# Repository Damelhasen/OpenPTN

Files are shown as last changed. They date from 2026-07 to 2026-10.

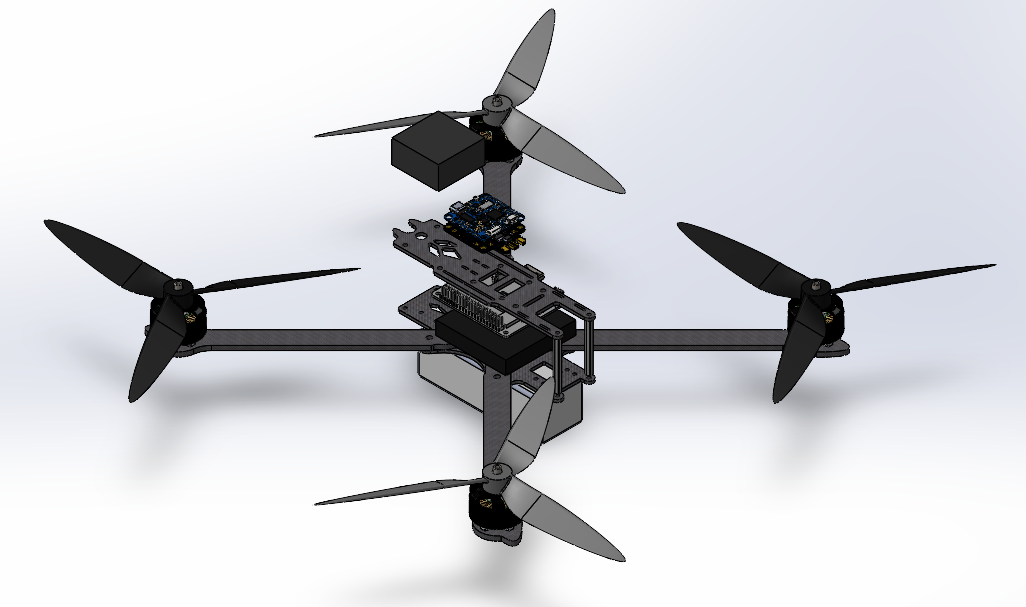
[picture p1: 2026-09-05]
images/drone.png

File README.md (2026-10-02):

  

# **OpenPTN : Radio Survey Drone**
  
The OpenPTN PTN radio survey drone aims to create a drone platform and payload that can complete autonomous flights while sampling directional radio signal strength across the spectrum to triangulate and map radio signals . Existing radio mapping and surveying tools are inaccessible to many due to their high costs and inefficiency due to their ground-based characteristics. 
# Use Cases
Radio surveying is used for:

**Search and Rescue**
-   Emergency Locator Transmitters (ELTs) from aircraft
-   Personal Locator Beacons (PLBs)
-   Emergency Position Indicating Radio Beacons (EPIRBs)

**Interference hunting**
-   Illegal FM Transmitter
-   GNSS jamming/spoofing
-   Malfunctioning Wireless Device
-   Interference Affecting Emergency Communications

**Telemetry tags**
- Wildlife and conservation tracking 
- Model Rocketry 

# System Diagram


# CAD Progress



# Current Hardware 
**Flight Controller**
- Matek H743-SLIM

**Power Distribution Board**
- Matek FCHUB-6S

**GPS Module**
- Matek M10Q GPS

**Electronic Speed Controller**
- Hobbywing XRotor 65A 4-in-1 BLHeli_32 ESC

**Software Defined Radios (SDRs)**
- RTL-SDR Blog V4 - Airspy Mini 

**Video Transmitter (VTX)**
 - AKK FX2 Ultimate 5.8 GHz (25–1000 mW)
 
 

 # Sponsorships

 **Banana Pi Team**

lion-wang-profile-picture-1566954273.avif

The Banana Pi Team has graciously donated their Banana Pi M2,Pro LCD and LED displays, and many other electrical components that will act as the processing unit for our SDR signals 

 **The London Model Aircraft Club**



The London Model Aircraft Club has donated to us:

-    Carbon Fibre Airframe
-   Flight controllers
-   Electronic Speed Controllers
-   Jumper T-16 Transmitter
-   GPS module
-  Radio Module
- Video Module and Camera 

  **RTL-SDR**

 
 
The RTL-SDR team has provided us with the RTL-SDR Starter Kit, which includes:

-   two sets of variable dipole antennas
-   a dipole mount
-   the RTL-SDR dongle
-   an RTL-SDR
-   an SMA extension cable

**Airspy**



The Airspy team has provided us with an Airspy mini dongle 

**AI USE **
Used to write Firmware and Copilot autofill**

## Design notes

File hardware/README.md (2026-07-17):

# MATEKSYS H743-Slim — ArduPilot Setup + Live IMU Dashboard

This documents the full process of getting a Matek H743-Slim flight controller
(factory-flashed with Betaflight) running ArduCopter and streaming live
attitude/GPS telemetry into a custom Python 3D dashboard (`instaimu.py`).

---

## 1. Hardware background

- Board: **Matek H743-Slim** (STM32H743 MCU)
- Ships from the factory with **Betaflight preloaded**, not ArduPilot — this
  is the root cause of most "no heartbeat" / "no MAVLink" issues on a fresh
  board.
- USB enumerates as an **STMicroelectronics Virtual COM Port** while running
  Betaflight (or any firmware using the STM32 USB CDC-ACM driver).
- Status LEDs: solid Red = power (3.3V rail), and normal ArduPilot boot state
  is typically a **flashing blue LED** (green/red solid, blue blinking) which
  means "disarmed, no GPS lock" — this is healthy, not a fault. A repeating
  **red-solid + blue/green alternating 3x** pattern specifically indicates the
  gyro/accelerometer wasn't detected on boot — that *is* a fault.

---

## 2. Windows driver / port setup

1. Plug the board into your PC via USB.
2. Open **Device Manager → Ports (COM & LPT)**.
3. Look for **STMicroelectronics Virtual COM Port (COMx)** — that's your board.
   Ignore Bluetooth serial links and unrelated management ports (e.g. Intel AMT).
4. If you get `OSError(22, 'The semaphore timeout period has expired.')` when
   opening the port:
   - Try a different USB cable (the #1 cause — many cables are charge-only)
   - Try a different USB port (avoid hubs/front-panel headers if possible)
   - Confirm nothing else (Mission Planner, another script, Arduino IDE) has
     the port open already

To list all serial ports and confirm which one is your board:
```powershell
py -c "import serial.tools.list_ports; [print(p.device, '-', p.description) for p in serial.tools.list_ports.comports()]"
```

---

## 3. Flashing ArduPilot (from factory Betaflight)

Since the board has no ArduPilot bootloader yet, Mission Planner's normal
"Install Firmware" flow can't talk to it directly. Instead, flash it at the
raw STM32 DFU level:

### 3.1 Download firmware
Get **`arducopter_with_bl.hex`** (bundles the ArduPilot bootloader + Copter
firmware in one file — needed for this first-time flash) from:
```
https://firmware.ardupilot.org/Copter/stable/MatekH743/
```
> Note: `MatekH743` may not always appear in Mission Planner's built-in board
> list depending on your Mission Planner version — the firmware server always
> has it directly, so this manual download path is the reliable option.

### 3.2 Enter DFU mode
1. Unplug USB
2. Hold the board's **BOOT** button (or bridge the BOOT pad per Matek's pinout
   if your revision doesn't have a physical button)
3. Plug in USB while still holding BOOT
4. Release after ~2 seconds
5. Device Manager should now show **"DFU in FS Mode"** under Universal Serial
   Bus devices (not a COM port anymore)

### 3.3 Driver for DFU mode (Zadig)
If STM32CubeProgrammer doesn't detect the board over USB:
1. Open **Zadig**
2. Select the **DFU** device from the dropdown (distinct from the STM32
   Virtual COM Port — don't touch that one)
3. Driver: **WinUSB**
4. Click **Replace Driver** (or **Install Driver**)

> ⚠️ Only use Zadig/WinUSB on the **DFU** device. Never replace the driver on
> the STM32 Virtual COM Port entry — that one needs to stay on `usbser` or
> Mission Planner/serial tools will lose it entirely.

### 3.4 Flash with STM32CubeProgrammer
Download: https://www.st.com/en/development-tools/stm32cubeprog.html

1. Open STM32CubeProgrammer, select **USB** as connection type, click
   **Connect** (should detect the board in DFU mode)
2. Go to **Erasing & Programming** tab
3. Browse to `arducopter_with_bl.hex`
4. Check **"Run after programming"** (jumps straight to the new firmware
   instead of requiring a manual power cycle)
5. Click **Start Programming**
6. Wait for a success message — the board will disconnect automatically once
   it starts running the new firmware

### 3.5 Confirm the flash
Check Device Manager again — you should now see an **ArduPilot** USB
composite device exposing (at least) two COM ports:
- One labeled **MAVLink** — use this one
- One labeled **SLCAN** — ignore this (CAN-bus passthrough, unrelated)

---

## 4. Connecting in Mission Planner

1. Select the **MAVLink** COM port (not SLCAN) in the top-right dropdown
2. Baud: **115200**
3. Click **Connect**
4. It should grab a heartbeat and pull parameters — this is the point where
   it finally works if you were stuck on Betaflight firmware before
5. Run through initial setup: frame type (e.g. Quad X), accelerometer
   calibration, compass calibration

If you still get `Sequence contains no elements` here, it almost always means
the FC isn't sending valid MAVLink yet — re-check the flash succeeded and the
correct (MAVLink, not SLCAN) port is selected.

---

## 5. Wireless connection options

Once wired setup works, to go wireless:

| Method | Range | Notes |
|---|---|---|
| **ESP8266/ESP32 WiFi bridge** | ~tens of m | Cheapest; wire to a spare UART, flash ArduPilot's WiFi bridge firmware, connect via UDP/TCP in Mission Planner |
| **Bluetooth (HC-05/HC-06)** | ~10m | Wire to spare UART, pairs as a normal Bluetooth COM port — works with existing scripts unchanged |
| **SiK radio (RFD900, HolyBro TX/RX)** | km-scale | Standard for actual flight telemetry; one radio on the FC, one on the PC via USB |
| **ExpressLRS/CRSF "Backpack"** | radio-link range | If your Jumper T16 runs ELRS or TBS Crossfire, an ELRS Backpack module taps the CRSF MAVLink passthrough and forwards it over WiFi to Mission Planner — no separate telemetry radio needed |

Check your T16's RF protocol under **Model Setup → Internal/External RF** —
CRSF/ELRS supports the Backpack route above; FrSky (D16/ACCESS) does not
support full MAVLink passthrough and would need one of the other methods.

---

## 6. Live IMU + GPS dashboard (`instaimu.py`)

A PyVista/Qt dashboard that renders a live 3D flying-wing model driven by
MAVLink `ATTITUDE` data, plus a GPS satellite counter and basic servo readout.

### 6.1 Install dependencies
```powershell
pip install pyvista pyvistaqt PyQt5 pymavlink pyserial numpy
```
> If you see `pyvista/pyvistaqt not installed` even after installing them,
> it usually means the Qt binding is missing — `pip install PyQt5` fixes it,
> since `pyvistaqt` needs an actual Qt backend to load, not just the package.

### 6.2 Run
```powershell
py instaimu.py
```
(or the full interpreter path if `py`/`python` aren't on PATH — see
Troubleshooting below)

### 6.3 Using it
- Pick your port from the dropdown (Refresh Ports if it's not listed) and hit
  **Connect**
- **Lock Yaw (Anti-Drift)**: locks the current yaw as a zero-reference so
  displayed yaw is relative, counteracting compass drift
- **Zero IMU (C)**: resets that same yaw reference on demand (also bound to
  the `C` key)
- Right panel shows live Roll/Pitch/Yaw, GPS satellite count + fix type, and a
  servo Left/Right readout (currently a placeholder elevon mix of pitch±roll
  — replace with your actual control mixing once wired to real surfaces)

### 6.4 How the smoothness/rate works
- Requests ATTITUDE @ 50Hz and GPS_RAW_INT @ 5Hz from the FC via
  `MAV_CMD_SET_MESSAGE_INTERVAL` (falls back to the older
  `REQUEST_DATA_STREAM` for old firmware)
- Dead-reckons orientation between MAVLink messages using the gyro rates
  already included in every `ATTITUDE` message, so the render loop (60fps via
  a Qt timer) always has a fresh angle rather than looking jittery between
  telemetry updates
- Rendering is GPU-accelerated via PyVista/VTK, not CPU-redrawn like
  matplotlib, so it holds a smooth frame rate

---

## 7. Troubleshooting quick reference

| Symptom | Likely cause / fix |
|---|---|
| `python was not found... Microsoft Store` | Windows Store alias shadowing real install — use `py` launcher, full interpreter path, or disable the alias in Settings → Apps → Advanced app settings → App execution aliases |
| `Sequence contains no elements` in Mission Planner | No valid MAVLink coming from the FC — usually still running Betaflight, or wrong COM port selected |
| `OSError(22, 'semaphore timeout...')` opening a port | Bad/charge-only USB cable, wrong port, or port already in use elsewhere |
| Port shows "DFU in FS Mode" instead of a COM port | Board is in DFU bootloader mode — expected during flashing, not for normal use |
| No heartbeat after flashing | Confirm you flashed `_with_bl.hex` (not the non-bootloader variant) and power-cycled after flashing |
| Two COM ports appear after flashing (MAVLink + SLCAN) | Normal — always connect to the one labeled **MAVLink** |
| `pyvista/pyvistaqt not installed` despite pip showing them installed | Missing Qt binding — `pip install PyQt5` |

---

## 8. File manifest

- `instaimu.py` — live IMU/GPS dashboard (PyVista + Qt), described in section 6

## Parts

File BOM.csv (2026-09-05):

Item Name | Qty | Price (total) (USD) | Item link | Notes
Carbon Fibre Frame | 1 | $6.70 | kitsguru.com/products/xI7-294mm-carbon-fiber-frame | This is an example part! Add things to note here.
1115KV Brushless Motor | 4 | $67.90 | https://tinyurl.com/2xaf9mwr | Requires reimbursment
Banana Pi BPI-M2 Pro |  | $135.43 | https://tinyurl.com/ydpc8rms | NO FUNDING NEEDED
Matek H743-SLIM-V4 | 1 | $125.99 | https://tinyurl.com/4z4pab75 | NO FUNDING NEEDED
MODULE M10Q-5883 GPS | 1 | $110.00 |  | NO FUNDING NEEDED
RTL-SDR Blog V4 | 1 | $91.84 | amazon.ca/RTL-SDR-Blog-RTL2832U-Software-Defined | NO FUNDING NEEDED
Q Brain 4 x 25A ESC | 1 | $29.99 |  | NO FUNDING NEEDED
14.8V 4S Lipo Battery 70C | 2 | $71.99 | https://tinyurl.com/ycxx3kaf
10CM 20CM Dupont Wire | 1 | $16.00 | https://tinyurl.com/2kncfued
SKYRC B6AC NEO Smart AC 60W DC 200W 10A Battery Balance Charger 1-6S Lipo LiFe Lilon LiHV 1-15S NiMH NiCd C55 | 1 | $61.09 | https://www.alibaba.com/pla/SKYRC-B6AC-NEO-Smart-AC-60W_1601630940480.html?mark=google_shopping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
Total Price (USD): | $716.93

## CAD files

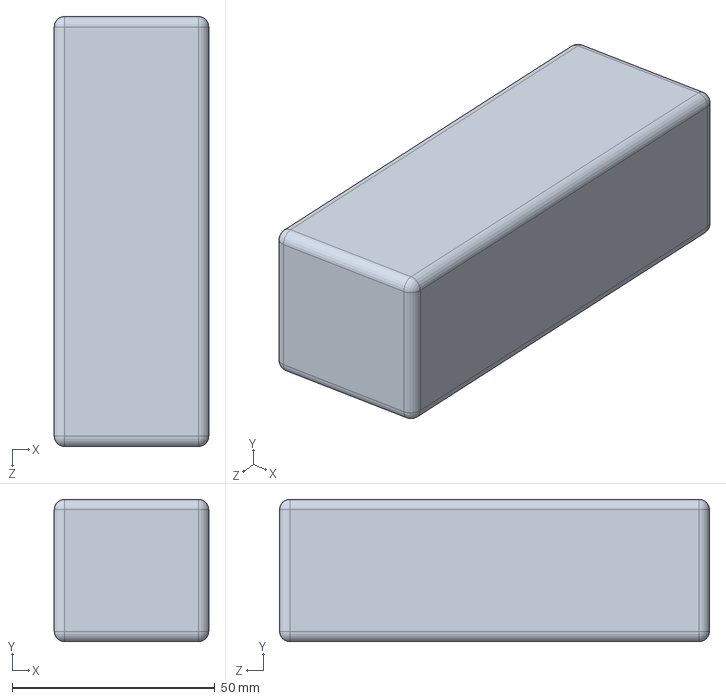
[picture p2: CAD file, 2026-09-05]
cad/Electronics/Battery Dimension Block.SLDPRT
38.1 x 35.1 x 106.0 mm

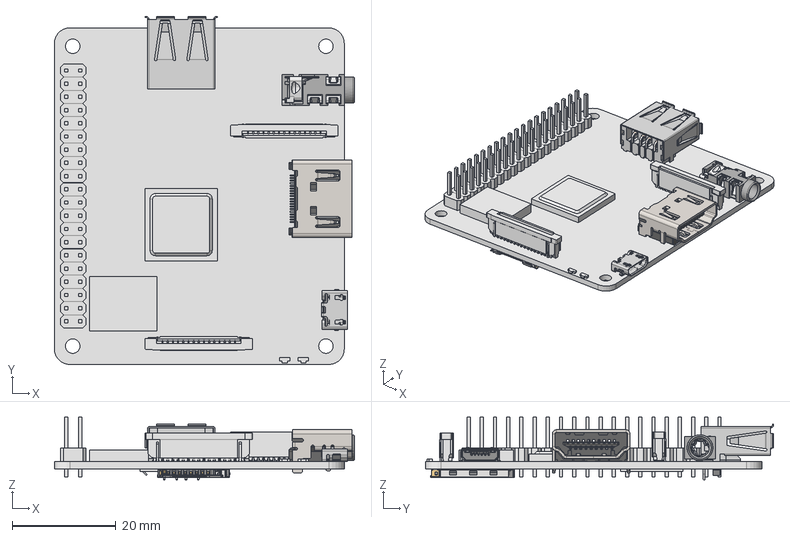
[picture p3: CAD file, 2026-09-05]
cad/Step files/RaspberryPi 3 A+.stp
58.0 x 67.2 x 12.1 mm
RaspberryPi Mainboard
RaspberryPi GPIO Pin x 20
HDMI port
usb001
usb002 x 4
usb000
Audio jack
FFC Connector x 2
Micro usb
Micro SD slot
CPU
Wireless Controller
Memory module
LED Indicator x 2

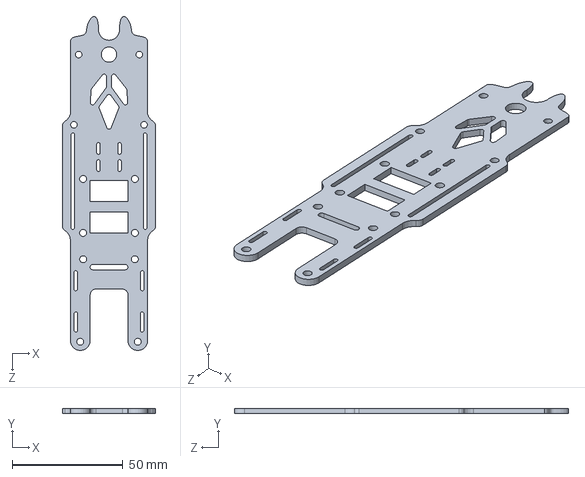
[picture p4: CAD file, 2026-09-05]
cad/Strcutural/Topframe.SLDPRT
42.3 x 2.38 x 151.1 mm

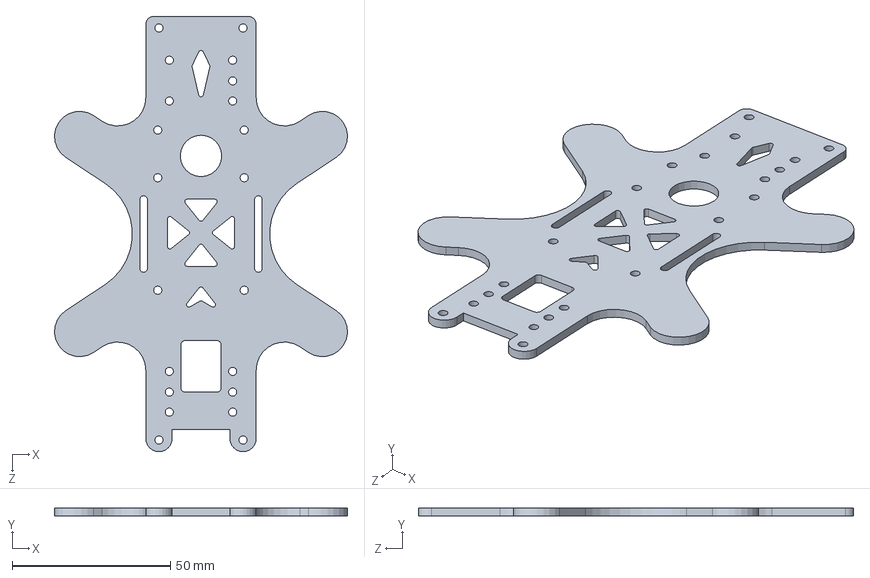
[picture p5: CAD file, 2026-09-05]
cad/Strcutural/Lowerframe.SLDPRT
92.7 x 2.38 x 137.7 mm

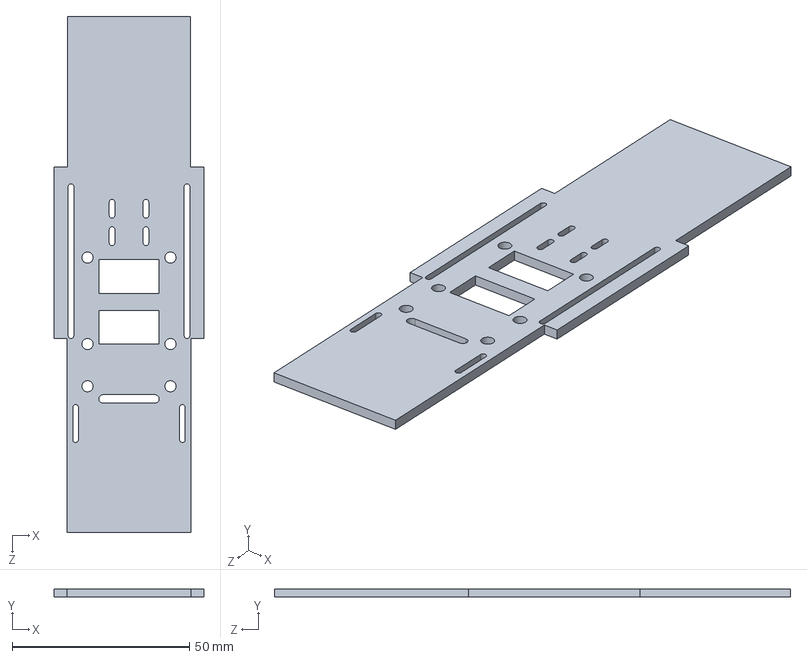
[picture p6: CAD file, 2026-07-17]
cad/Topframe.SLDPRT
42.3 x 2.38 x 145.7 mm

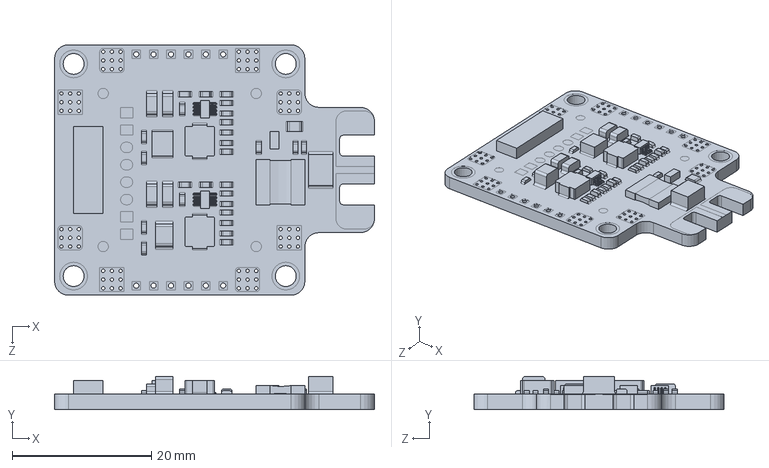
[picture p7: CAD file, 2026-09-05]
cad/Electronics/PDB.SLDPRT
46.0 x 4.75 x 36.0 mm

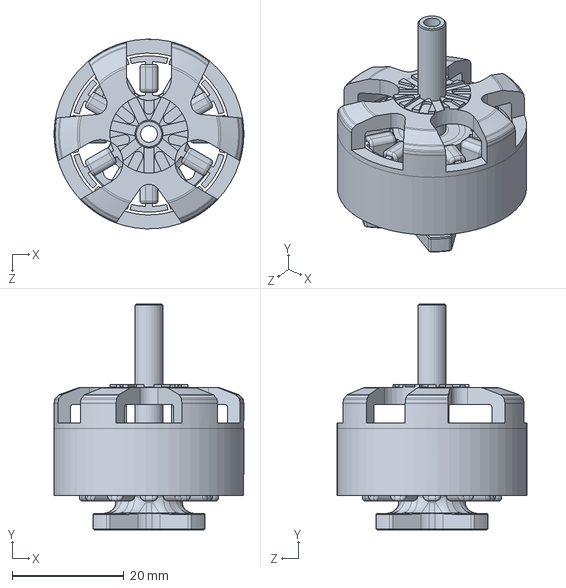
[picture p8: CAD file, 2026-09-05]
cad/Electronics/HOBBYWING2812.SLDPRT
34.0 x 40.5 x 34.0 mm

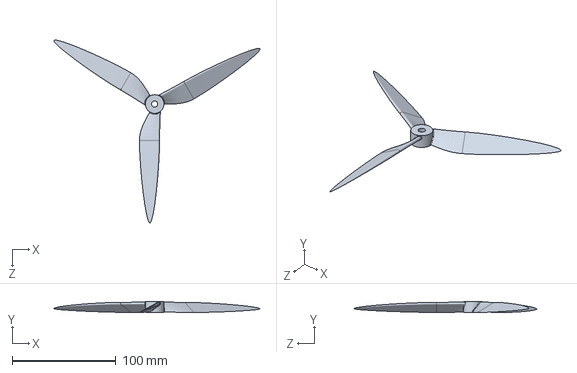
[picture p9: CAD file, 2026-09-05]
cad/Strcutural/FAB_PROPELLER - 9x4.5 CCW.sldprt
198.1 x 11.0 x 175.7 mm

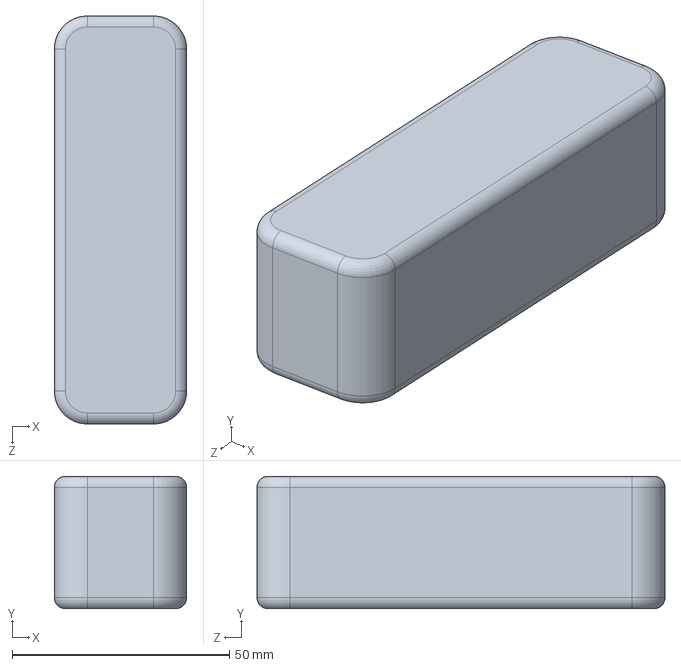
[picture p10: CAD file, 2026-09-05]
cad/Electronics/PowerBank dimension block.SLDPRT
30.5 x 30.5 x 94.0 mm

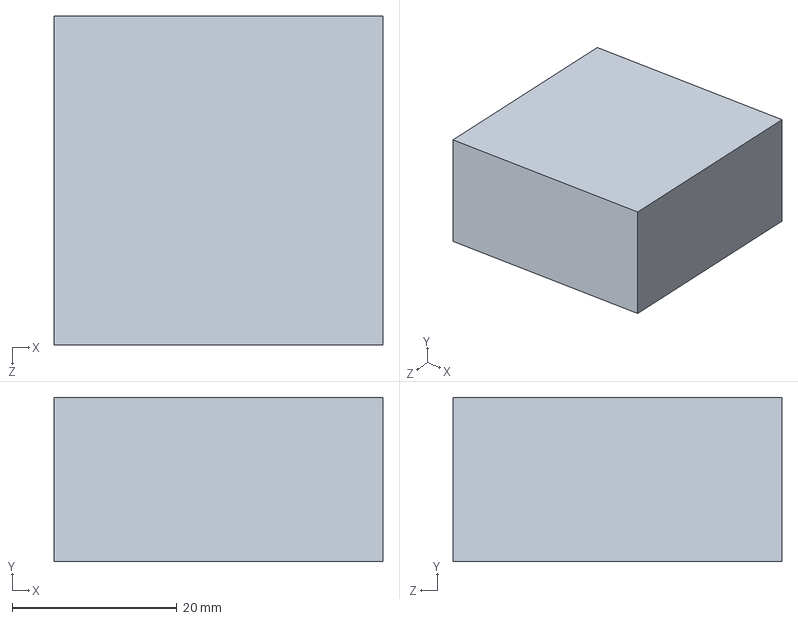
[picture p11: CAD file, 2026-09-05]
cad/Electronics/Ecompass dimension block.SLDPRT
40.0 x 20.0 x 40.0 mm

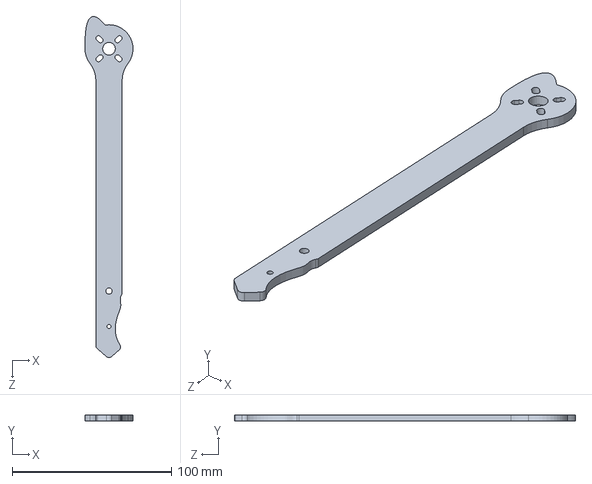
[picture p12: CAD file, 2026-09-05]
cad/Strcutural/Wing.SLDPRT
30.2 x 3.97 x 213.9 mm

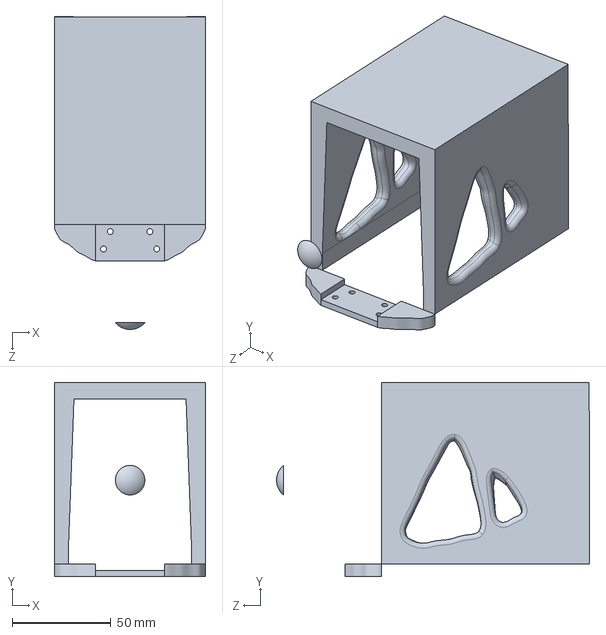
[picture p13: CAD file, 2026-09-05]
cad/Strcutural/PL frame.SLDPRT
76.6 x 98.6 x 158.6 mm

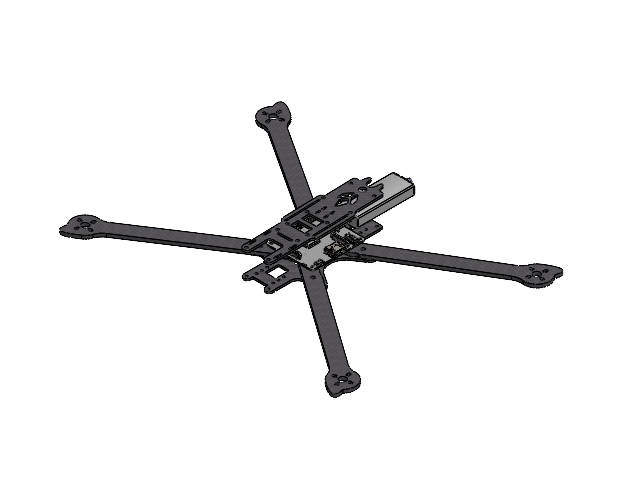
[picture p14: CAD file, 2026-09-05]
cad/Drone assm.SLDASM
Lowerframe
Wing x 4
Topframe
usb001.stp
usb002.stp x 4
usb000.stp
RaspberryPi Mainboard.stp
RaspberryPi GPIO Pin.stp x 20
HDMI port.stp
Audio jack.stp
FFC Connector.stp x 2
Micro usb.stp
Micro SD slot.stp
CPU.stp
Wireless Controller.stp
Memory module.stp
LED Indicator.stp x 2
main_body.step
face_sma.step
face_usb.step
sma_jack.step

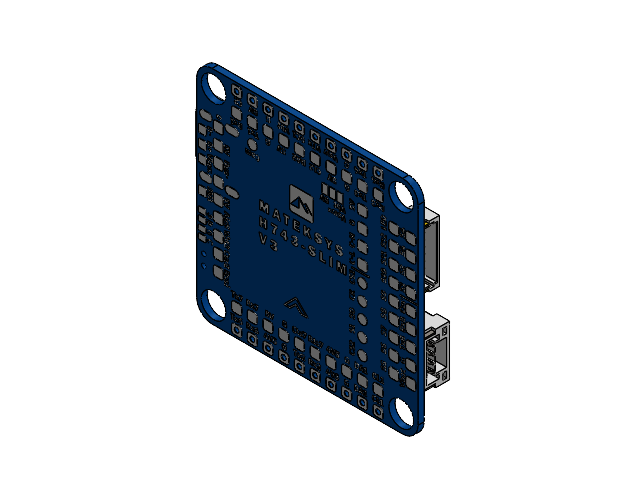
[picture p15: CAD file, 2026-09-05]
cad/Electronics/MATEKSYS H743-SLIM V3.SLDASM
SM8B-SRSS-TB v1 (1).step
Chip 3 (2).step x 3
USB Type C Port (SMD Type) v1.step
475710001_uSD_holder v1.step
SM04B-GHS-TB v1.step
S00123.step x 2
Transistor.step x 2
5V Reg.step x 2
Chip (2).step
H743.step
Chip (3).step
5V Reg (1).step
ICM42605.step x 2
1TS003B v1.step
Misc.step
LED.step
LED (1).step
LED (2).step
Chips (1)-0.step
Chips (1)-1.step
Chips (1)-2.step
Chips (1)-3.step
Chips (1)-4.step
Chips (1)-5.step
Chips (1)-6.step
Chips (1)-7.step
Chips (1)-8.step
Chips (1)-9.step
Chips (1)-10.step
Chips (1)-11.step
Chips (1)-12.step
Chips (1)-13.step
Chips (1)-14.step
Chips (1)-15.step
Chips (1)-16.step
Chips (1)-17.step
Chips (1)-18.step
Chips (1)-19.step
Chips (1)-20.step
Chips (1)-21.step
Chips (1)-22.step
Chips (1)-23.step
Chips (1)-24.step
Chips (1)-25.step
Chips (1)-26.step
Chips (1)-27.step
Chips (1)-28.step
Chips (1)-29.step
Chips (1)-30.step
Chips (1)-31.step
Chips (1)-32.step
Chips (1)-33.step
Chips (1)-34.step
Chips (1)-35.step
Chips (1)-36.step
Chips (1)-37.step
Chips (1)-38.step
Chips (1)-39.step
Chips (1)-40.step
Chips (1)-41.step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

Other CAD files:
cad/Electronics/RTL_SDR.SLDASM
cad/Electronics/RaspberryPi 3 A+.SLDASM
cad/Strcutural/PL Topframe.SLDPRT
cad/Strcutural/FAB_PROPELLER - 9x4.5 CW.sldprt
cad/Strcutural/91780A552_Lightweight Aluminum Female Threaded Hex Standoff.SLDPRT

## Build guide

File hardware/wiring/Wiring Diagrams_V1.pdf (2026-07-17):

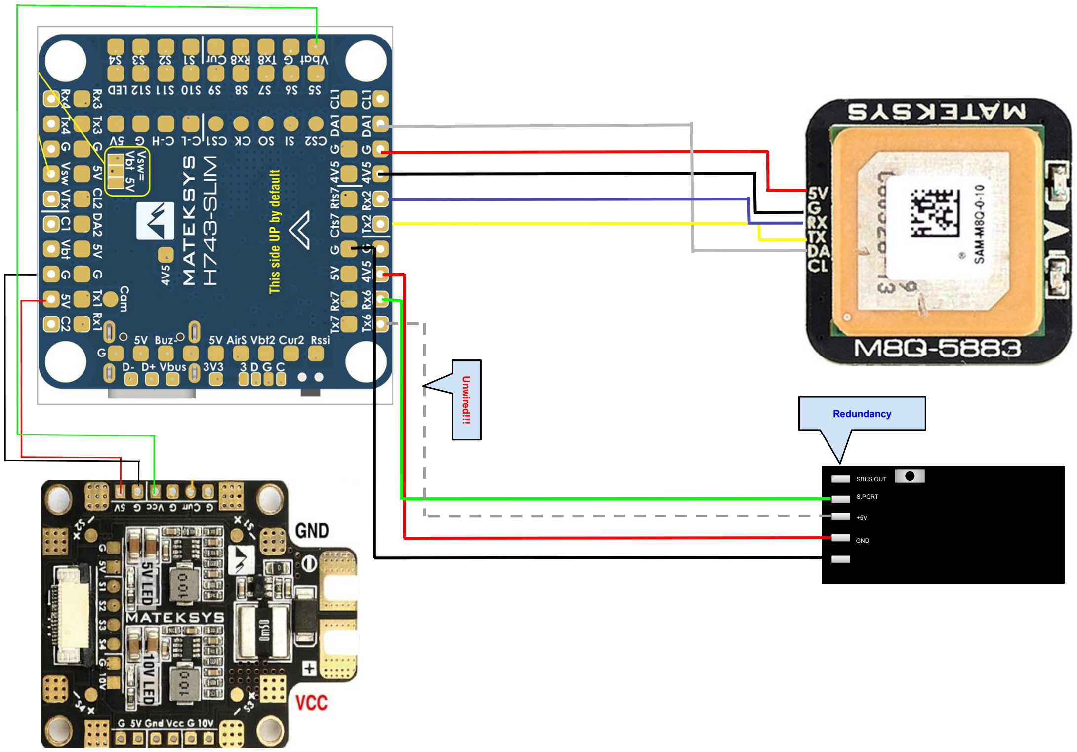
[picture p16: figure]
SBUS IN; SBUS OUT; S.PORT; GND; Unwired!!!; Redundancy

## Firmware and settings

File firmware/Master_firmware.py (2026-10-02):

#!/usr/bin/env python3

import argparse
import csv
import http.server
import ipaddress
import json
import math
import socket
import time
import threading
from pymavlink import mavutil
from datetime import datetime, timezone
from pathlib import Path
import webbrowser

try:
    from rtlsdr import RtlSdr
except ImportError:
    RtlSdr = None
import numpy as np

CSV_FIELDS = (
    "timestamp_utc",
    "frequency_hz",
    "gps_time_usec",
    "fix_type",
    "latitude_deg",
    "longitude_deg",
    "altitude_m",
    "relative_altitude_m",
    "position_time_boot_ms",
    "roll_deg",
    "pitch_deg",
    "yaw_deg",
    "attitude_time_boot_ms",
    "attitude_timestamp_utc",
    "eph_m",
    "epv_m",
    "ground_speed_m_s",
    "course_deg",
    "satellites_visible",
    "signal_power_dbfs",
)


def parse_args():
    parser = argparse.ArgumentParser(
        description="Scan radio signal strength along a GPS track."
    )
    parser.add_argument("--frequency-mhz", type=float)
    parser.add_argument("--output")
    parser.add_argument("--port", default="/dev/ttyACM0")
    parser.add_argument("--baud", type=int, default=115200)
    parser.add_argument("--sample-count", type=int, default=256 * 1024)
    parser.add_argument("--gps-rate-hz", type=float, default=5.0)
    parser.add_argument("--dashboard-port", type=int, default=8765)
    args = parser.parse_args()
    if args.frequency_mhz is not None and args.frequency_mhz <= 0:
        parser.error("--frequency-mhz must be greater than zero")
    if args.sample_count <= 0 or args.gps_rate_hz <= 0 or args.baud <= 0:
        parser.error("sample count, GPS rate, and baud must be greater than zero")
    if not 1 <= args.dashboard_port <= 65535:
        parser.error("dashboard port must be between 1 and 65535")
    return args


def ask_positive_number(prompt: str) -> float:
    while True:
        try:
            value = float(input(prompt))
            if value > 0:
                return value
        except ValueError:
            pass
        print("Enter a number greater than zero.")


def collect_scan_settings(args):
    frequency_mhz = args.frequency_mhz
    if frequency_mhz is None:
        frequency_mhz = ask_positive_number("Target frequency (MHz): ")

    now = datetime.now().astimezone()
    output_path = Path(
        args.output or "dronescan_{}.csv".format(now.strftime("%Y%m%d_%H%M%S"))
    ).expanduser()
    return frequency_mhz, output_path


def listen_freq(sdr_device, frequency_hz: float, sample_count: int) -> float:
    sdr_device.center_freq = frequency_hz
    samples = sdr_device.read_samples(sample_count)
    mean_power = float(np.mean(np.abs(samples) ** 2))
    return 10 * math.log10(max(mean_power, 1e-12))


def gps_row(
    message,
    frequency_hz: float,
    signal_power_dbfs: float,
    attitude,
    global_position,
) -> dict:
    return {
        "timestamp_utc": datetime.now(timezone.utc).isoformat(),
        "frequency_hz": frequency_hz,
        "gps_time_usec": message.time_usec,
        "fix_type": message.fix_type,
        "latitude_deg": message.lat / 1e7 if abs(message.lat) <= 900000000 else "",
        "longitude_deg": message.lon / 1e7 if abs(message.lon) <= 1800000000 else "",
        "altitude_m": message.alt / 1000,
        "relative_altitude_m": (
            global_position["relative_altitude_m"] if global_position else ""
        ),
        "position_time_boot_ms": global_position["time_boot_ms"] if global_position else "",
        "roll_deg": attitude["roll_deg"] if attitude else "",
        "pitch_deg": attitude["pitch_deg"] if attitude else "",
        "yaw_deg": attitude["yaw_deg"] if attitude else "",
        "attitude_time_boot_ms": attitude["time_boot_ms"] if attitude else "",
        "attitude_timestamp_utc": attitude["timestamp_utc"] if attitude else "",
        "eph_m": message.eph / 100,
        "epv_m": message.epv / 100,
        "ground_speed_m_s": message.vel / 100,
        "course_deg": message.cog / 100,
        "satellites_visible": message.satellites_visible,
        "signal_power_dbfs": signal_power_dbfs,
    }


def create_heat_map(csv_path: Path):
    import folium
    from folium.plugins import HeatMap

    if not csv_path.exists():
        return None

    points = []
    with csv_path.open("r", newline="", encoding="utf-8") as log_file:
        for row in csv.DictReader(log_file):
            try:
                latitude = float(row["latitude_deg"])
                longitude = float(row["longitude_deg"])
                fix_type = int(row["fix_type"])
                power = float(row["signal_power_dbfs"])
            except (KeyError, TypeError, ValueError):
                continue
            if fix_type >= 2 and -90 <= latitude <= 90 and -180 <= longitude <= 180:
                points.append((latitude, longitude, power))

    if not points:
        return None

    powers = [point[2] for point in points]
    minimum_power = min(powers)
    maximum_power = max(powers)
    power_range = maximum_power - minimum_power
    heat_points = [
        [latitude, longitude, (power - minimum_power) / power_range if power_range else 1]
        for latitude, longitude, power in points
    ]
    center = [
        sum(point[0] for point in points) / len(points),
        sum(point[1] for point in points) / len(points),
    ]

    signal_map = folium.Map(location=center, zoom_start=17, control_scale=True)
    HeatMap(
        heat_points,
        radius=22,
        blur=18,
        min_opacity=0.2,
        max_zoom=19,
    ).add_to(signal_map)
    legend = """
    <div style="position:fixed;bottom:28px;left:28px;z-index:9999;background:white;padding:10px 12px;border:1px solid #777;font:13px sans-serif">
      <b>Signal power (dBFS)</b><br>
      Weaker: {minimum:.1f} &nbsp; | &nbsp; Stronger: {maximum:.1f}<br>
      Heat intensity is relative within this scan.
    </div>
    """.format(minimum=minimum_power, maximum=maximum_power)
    signal_map.get_root().html.add_child(folium.Element(legend))

    map_path = csv_path.with_suffix(".html")
    signal_map.save(str(map_path))
    return map_path


def dashboard_snapshot(state, state_lock):
    with state_lock:
        snapshot = {
            key: value for key, value in state.items() if key != "raw_points"
        }
        points = list(state["raw_points"])

    if points:
        powers = [point[2] for point in points]
        minimum_power = min(powers)
        maximum_power = max(powers)
        power_range = maximum_power - minimum_power
        snapshot["points"] = [
            [latitude, longitude, (power - minimum_power) / power_range if power_range else 1]
            for latitude, longitude, power, _ in points
        ]
        snapshot["track_points"] = [
            [latitude, longitude, power, timestamp]
            for latitude, longitude, power, timestamp in points
        ]
        snapshot["minimum_power_dbfs"] = minimum_power
        snapshot["maximum_power_dbfs"] = maximum_power
    else:
        snapshot["points"] = []
        snapshot["track_points"] = []
        snapshot["minimum_power_dbfs"] = None
        snapshot["maximum_power_dbfs"] = None

    snapshot["map_url"] = "/final-map" if snapshot.get("map_path") else None
    return snapshot


def local_network_ip() -> str:
        probe = socket.socket(socket.AF_INET, socket.SOCK_DGRAM)
        try:
                probe.connect(("192.0.2.1", 80))
                address = probe.getsockname()[0]
                if not ipaddress.ip_address(address).is_loopback:
                        return address
        except OSError:
                pass
        finally:
                probe.close()

        for result in socket.getaddrinfo(socket.gethostname(), None, socket.AF_INET):
                address = result[4][0]
                if not ipaddress.ip_address(address).is_loopback:
                        return address
        return "127.0.0.1"


def start_dashboard(state, state_lock, port: int):
        page = """<!doctype html>
<html lang="en">
<head>
    <meta charset="utf-8">
    <meta name="viewport" content="width=device-width, initial-scale=1">
    <title>DroneScan Live</title>
    <link rel="stylesheet" href="https://unpkg.com/leaflet@1.9.4/dist/leaflet.css">
    <style>
        :root { color-scheme: light; font: 15px/1.45 system-ui, sans-serif; }
        * { box-sizing: border-box; }
        body { margin: 0; color: #14201f; background: #edf1ee; }
        header { display: flex; flex-wrap: wrap; align-items: center; gap: 16px 28px;
            padding: 14px 20px; background: #173b35; color: #fff; }
        h1 { margin: 0; font-size: 19px; font-weight: 650; }
        #status { padding: 4px 9px; border: 1px solid #83c8a9; border-radius: 3px; color: #c8f2d9; }
        #stats { display: flex; flex-wrap: wrap; gap: 8px 22px; margin-left: auto; }
        #stats span { white-space: nowrap; }
        main { padding: 14px; }
        #map { width: 100%; height: calc(100vh - 115px); min-height: 360px; border: 1px solid #bdc9c4; }
        #legend { position: absolute; right: 28px; bottom: 28px; z-index: 1000; padding: 9px 12px;
            background: #fff; border: 1px solid #89958f; font-size: 13px; }
        #final-link { display: none; color: #145e48; }
        @media (max-width: 600px) { header { gap: 8px 14px; } #stats { margin-left: 0; } main { padding: 8px; } #map { height: calc(100vh - 155px); } }
    </style>
</head>
<body>
    <header>
        <h1>DroneScan</h1><span id="status">Connecting</span>
        <div id="stats">
            <span>Frequency <b id="frequency">--</b></span>
            <span>Local time <b id="clock">--</b></span>
            <span>Samples <b id="samples">0</b></span>
            <span>Current <b id="current">--</b></span>
            <span>GPS <b id="gps">--</b></span>
            <span>Altitude <b id="altitude">--</b></span>
            <span>Attitude <b id="attitude">--</b></span>
            <span>Last fix <b id="last-fix">--</b></span>
            <a id="final-link" href="/final-map" target="_blank" rel="noopener">Open saved map</a>
        </div>
    </header>
    <main><div id="map"></div></main>
    <div id="legend">Signal power (dBFS)<br><span id="range">Waiting for samples</span><br>Heat is relative within this scan.</div>
    <script src="https://unpkg.com/leaflet@1.9.4/dist/leaflet.js"></script>
    <script src="https://unpkg.com/leaflet.heat/dist/leaflet-heat.js"></script>
    <script>
        const map = L.map('map').setView([0, 0], 2);
        L.tileLayer('https://{s}.tile.openstreetmap.org/{z}/{x}/{y}.png', {
            maxZoom: 19, attribution: '&copy; OpenStreetMap contributors'
        }).addTo(map);
        const heat = L.heatLayer([], {radius: 24, blur: 18, minOpacity: 0.2,
            gradient: {0.2: '#3288bd', 0.45: '#abdda4', 0.7: '#fdae61', 1: '#d53e4f'}}).addTo(map);
        const markers = L.layerGroup().addTo(map);
        let centered = false;
        let markerCount = 0;
        function updateClock() {
            document.getElementById('clock').textContent = new Date().toLocaleTimeString();
        }
        async function refresh() {
            try {
                const response = await fetch('/api/status', {cache: 'no-store'});
                const data = await response.json();
                document.getElementById('status').textContent = data.status;
                document.getElementById('frequency').textContent = `${data.frequency_mhz} MHz`;
                document.getElementById('samples').textContent = data.rows;
                document.getElementById('current').textContent = data.current_power_dbfs === null
                    ? '--' : Number(data.current_power_dbfs).toFixed(1) + ' dBFS';
                document.getElementById('gps').textContent = data.current_gps || '--';
                document.getElementById('altitude').textContent = data.current_altitude_m === null
                    ? '--' : `${Number(data.current_altitude_m).toFixed(1)} m MSL / ${data.current_relative_altitude_m === null ? '--' : Number(data.current_relative_altitude_m).toFixed(1) + ' m rel'}`;
                document.getElementById('attitude').textContent = data.current_attitude || '--';
                document.getElementById('last-fix').textContent = data.last_sample_time_utc
                    ? new Date(data.last_sample_time_utc).toLocaleTimeString() + ' local'
                    : '--';
                document.getElementById('range').textContent = data.minimum_power_dbfs === null
                    ? 'Waiting for samples' : `${Number(data.minimum_power_dbfs).toFixed(1)} to ${Number(data.maximum_power_dbfs).toFixed(1)} dBFS`;
                heat.setLatLngs(data.points);
                for (const point of data.track_points.slice(markerCount)) {
                    const marker = L.circleMarker([point[0], point[1]], {
                        radius: 4, color: '#173b35', weight: 1, fillOpacity: 0.85
                    });
                    const popup = document.createElement('div');
                    popup.textContent = `${new Date(point[3]).toLocaleString()} · ${Number(point[2]).toFixed(1)} dBFS`;
                    marker.bindPopup(popup).addTo(markers);
                }
                markerCount = data.track_points.length;
                if (!centered && data.points.length) {
                    map.setView([data.points[0][0], data.points[0][1]], 18);
                    centered = true;
                }
                if (data.map_url) document.getElementById('final-link').style.display = 'inline';
            } catch (error) {
                document.getElementById('status').textContent = 'Reconnecting';
            }
        }
        updateClock();
        setInterval(updateClock, 1000);
        refresh();
        setInterval(refresh, 1000);
    </script>
</body>
</html>"""

        class DashboardHandler(http.server.BaseHTTPRequestHandler):
                def log_message(self, format_string, *args):
                        pass

                def send_body(self, body: bytes, content_type: str):
                        self.send_response(200)
                        self.send_header("Content-Type", content_type)
                        self.send_header("Content-Length", str(len(body)))
                        self.send_header("Cache-Control", "no-store")
                        self.end_headers()
                        self.wfile.write(body)

                def do_GET(self):
                        if self.path == "/":
                                self.send_body(page.encode("utf-8"), "text/html; charset=utf-8")
                        elif self.path == "/api/status":
                                payload = json.dumps(dashboard_snapshot(state, state_lock)).encode("utf-8")
                                self.send_body(payload, "application/json; charset=utf-8")
                        elif self.path == "/final-map":
                                snapshot = dashboard_snapshot(state, state_lock)
                                map_path = snapshot.get("map_path")
                                if map_path and Path(map_path).is_file():
                                        self.send_body(Path(map_path).read_bytes(), "text/html; charset=utf-8")
                                else:
                                        self.send_error(404, "The scan heat map is not ready yet")
                        else:
                                self.send_error(404)

        server = http.server.ThreadingHTTPServer(("0.0.0.0", port), DashboardHandler)
        server.daemon_threads = True
        thread = threading.Thread(target=server.serve_forever, daemon=True)
        thread.start()
        dashboard_url = "http://{}:{}/".format(local_network_ip(), port)
        return server, dashboard_url
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

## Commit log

2026-07-02 Add simulation, CAD, and project infrastructure
2026-07-07 VERY rough draft of top frame of base quadcopter
    [Topframe.SLDPRT]
2026-07-15 added wiring diagram V1
2026-07-21 Addes Jan's CAD files
    [Lowerframe.SLDPRT, PDB.SLDPRT, RTL_SDR.SLDASM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]
2026-07-21 Initialize README with project details and sponsorships
    Added detailed project description, use cases, system diagram, CAD progress, current hardware specifications, and sponsorship information.
2026-08-16 Revise and restore README.md content
    Restored and updated content in README.md for the OpenPTN Radio Survey Drone project, including use cases, system diagram, CAD progress, current hardware, and sponsorship details.
2026-09-04 Add files via upload
    Added BOM to root
    [BOM - Sheet1.csv]
2026-09-04 Rename BOM - Sheet1.csv to BOM.csv
    [BOM.csv]
2026-09-05 Updated Drone assembly
2026-10-02 Added step folder to repo
    [RaspberryPi 3 A+.stp]
2026-10-31 Made a function and tester.py that takes in a CSV and generates a heat map HTML. Also made a tester CSV file to test this function on. Will later move it to the main AlphaOS Python file.
2026-10-31 Revise project details and sponsorship information in README
    Updated README.md to reflect current project details and sponsorships, including AI usage clarification.
2026-11-02 Modify loop to run indefinitely while motors armed
    Changed the loop condition to always run while motors are armed.
